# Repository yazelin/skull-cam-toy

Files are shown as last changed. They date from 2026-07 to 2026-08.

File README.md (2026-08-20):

# 骷髏頭凸輪玩具

一根手搖軸、四片凸輪、四個動作(下顎開合、點頭、眼球、轉頭)的木製凸輪機構玩具。

起因是一份 **AI 產生的 1:1 裁切樣板 PDF**。圖面乍看很完整 —— 尺寸線、鑽孔中心、
組裝順序、相位圖全都有,但把向量座標解出來重算之後發現**做不出來**:七個致命問題,
其中「轉頭」那一路即使零件全部完美裁切,自由度也是 0。

這個 repo 是重新推導、逐項驗證過的版本,含 3D 模擬、驗證腳本,以及可以直接下雷切的 1:1 檔案。

**網站:** https://yazelin.github.io/skull-cam-toy/

---

## 拿去做

| | |
|---|---|
| [`cut/cut-all-A4.pdf`](cut/cut-all-A4.pdf) | 1:1 切割檔,A4 五頁,共 47 片 |
| [`cut/cut-*.dxf`](cut/) | 同上的 DXF(雷射軟體通吃,單位 mm) |
| [`cut/cut-*.svg`](cut/) | 同上的 SVG(黑線=切割、藍字=刻字) |
| [`ASSEMBLY.md`](ASSEMBLY.md) | 組裝說明書,十步,每步附「怎麼驗」 |
| [`FINDINGS.md`](FINDINGS.md) | 驗證報告:原始圖面哪裡壞、修正版怎麼驗的 |

材料:3mm 合板 + **只剩兩支圓棒**(Ø6 凸輪軸、Ø4 轉盤撥銷)+ 8×6 方棒(頸脊)+ **兩條橡皮筋**(非加不可,理由見報告)。
導柱、滑銷、軸環全部改成板材卡榫。

每張切割檔底部都有 50mm 校正尺。切之前先量它。

---

## 網站頁面

| 檔案 | 內容 |
|---|---|
| `index.html` | 概覽。招牌是四片**真實凸輪輪廓**在同一根軸上同步轉動,資料就是模擬器用的那一份 |
| `sim.html` | 3D 模擬。可切「原始圖面 / 修正版」,右側有 15 項幾何檢查與完整約束盤點 |
| `heart.html` | **七夕限定「心跳凸輪」**:一片偏心凸輪+一顆會跳的心,20 片 3mm 板、一張 A4 的入門版。含 3D 模擬與 8 項整圈幾何檢查;切割檔 `cut/heart-cut-1.svg/.dxf` 由 `node export-heart.js` 從模型產生;干涉掃描 `node heart-collide.js`(36 角度全零件對,抓過一次相位反向)。模擬全過,**還沒實際切過** |
| `heart-assembly.html` | 由 `HEART-ASSEMBLY.md` 產生:七步組裝+每步驗收+防呆五清單 |
| `heart-print.html` | 心跳凸輪 **3D 列印原生版**:9 種零件印 10 件、全程免膠(D 型軸傳扭力/頂蓋壓入/間隔套定位)。STL 在 `print/`,由 `node export-heart-print-stl.js` 產生;干涉掃描 `node heart-print-collide.js` |
| `heart-print-assembly.html` | 由 `HEART-PRINT-ASSEMBLY.md` 產生:免膠組裝五步+每步 3D 完成狀態圖 |
| `DESIGN-RULES.md` | 機構設計規則檢查表(接頭/配合/導引/約束/驗證順序),新機構動工前逐條過 |
| `assembly.html` | 由 `ASSEMBLY.md` 產生 |
| `findings.html` | 由 `FINDINGS.md` 產生 |

`assembly.html` 與 `findings.html` 是**產生出來的**,不要直接改;改 `.md` 之後跑 `node build-site.js`。

---

## 程式與工具

| 檔案 | 做什麼 |
|---|---|
| `mech.js` | 運動學核心、15 項幾何檢查、約束盤點表(`DOF`) |
| `profiles.js` | 從樣板 PDF 的貝茲曲線解出來的真實輪廓(頭骨、下顎、兩片凸輪) |
| `sim.html` | three.js 場景。每片木板都登記自己的「2D 外形 + 孔 + 厚度」,供掃描與出圖用 |
| `collide.js` | 干涉掃描:板內佈 1mm 網格取樣點,曲柄轉一圈取 72 個角度,兩兩互測 |
| `bom.js` | 從模型撈零件表 |
| `export-cut.js` | 從模型產生 SVG + DXF 切割檔 |
| `build-site.js` | Markdown → 網站頁面 |

全部需要本機 HTTP:

```bash
python3 -m http.server 8099        # 然後開 http://127.0.0.1:8099/
node collide.js                     # 干涉掃描
node bom.js                         # 零件表
node export-cut.js                  # 重出切割檔
node build-site.js                  # 重出網站頁面
```

**切割檔是從 3D 模型直接撈出來的,不是另外畫的** —— 模型改了重跑一次就同步,不會有「圖跟模型對不起來」的問題。

---

## 目前的驗證狀態

```
零件自檢                 每個孔都完全落在輪廓內
肉厚自檢                 孔↔孔、孔↔輪廓都 ≥ 2mm
單件自檢                 沒有「同一零件被拆成多片」
15 項幾何檢查            全過
41 片木板 / 136,125 點    轉一圈 72 個角度   零干涉
四組凸輪接觸間隙          0.00 mm
轉頭叉口                  上緣 0.20 / 下緣 0.20 mm,叉底剩 3.0 mm
約束盤點                  只剩兩處力封閉(下顎、眼球推桿)→ 用橡皮筋
```

還沒做:實際切過。榫孔留單邊 0.1mm,雷射有割縫可能偏鬆,建議先切一組榫試配。

---

## 授權

MIT © 林亞澤。原始樣板 PDF 的著作權屬原作者;本 repo 的幾何是重新推導的。

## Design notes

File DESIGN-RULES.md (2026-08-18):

# 機構設計規則(從骷髏頭與心跳凸輪的實戰蒸餾)

新機構動工前逐條過;這是設計檢查表,不是事後參考。每條都對應一次真實翻車。

## 接頭
- 薄板**對接黏不住**:任何「一條邊碰一條面」的接法,膠合面積趨近零 → 一律榫接/搭接/叉夾,要有互穿的料。(骷髏下顎受推板 0mm²;心跳假接頭)
- 十字/錯位搭接:兩邊的槽**不能疊在同一段空腔**,要錯開,讓 A 的實心填 B 的槽、B 的實心填 A 的槽。畫完自問:**x、y、z 三個方向各由哪個面擋住?**答不出來的方向就是會掉的方向。
- 尖的、窄的零件別在尖端開槽:先確認開槽處的實際料寬(從輪廓量,不是想像)。

## 配合與間隙
- 滑動配合:單邊 0.3mm 起跳(3mm 板實證值);膠合定位配合:單邊 0.1~0.2。
- **任何「靠緊、貼緊」的組裝指令 = 零間隙警報**:自治具黏法要寫墊隙(桿身包一層紙,乾後抽掉)。
- 板材標 3mm 實際 2.8~3.2;疊層會再加誤差。指南要寫「疊完磨齊、裝前試滑」。
- 雷切 kerf 讓配合再鬆 0.1~0.2:留隙+上膠的設計吃得下,緊配吃不下。

## 滑動導引
- 導引嚙合深度 vs 懸臂(抽屜法則):懸臂/嚙合 > 2.5 會卡死(木件上蠟)。單一 3mm 板厚的槽幾乎一定不夠,要導套或雙導點。
- 接觸點會游走的(偏心凸輪 ±e),承接面寬度 = 游走範圍 + 兩側各 ≥2mm。
- 軸向對位靠「加寬其中一方」吃公差:凸輪比推桿厚 ≥2mm,黏歪也磨得到。

## 約束
- 干涉掃描證明「不會穿過」,**不證明「被固定住」**:每個動件 6 個自由度逐一問靠什麼擋,分「形封閉(形狀,拿不掉)」與「力封閉(重力/彈力,快搖會脫)」。力封閉處寫明回位方案(自重/橡皮筋)。
- 手搖類:手把整圈掃過的空間要淨空(對桌面、對底板、對箱體)。

## 驗證順序(每次幾何改動都跑,不是完工才跑)
1. 零件自檢:孔在輪廓內、肉厚 ≥2mm、輪廓不自交、同名件不拆片
2. 干涉掃描:全零件對 × 整圈角度,取樣點互測
3. 幾何檢查:行程、間隙、防卡滯比,寫成頁面常駐項
4. **接頭特寫目視**:合體+拆解各截一張,親眼確認咬合
5. 相位/方向不用手推符號:從 matrixWorld 取實點驗證
6. 改參數名 grep 全檔零殘留(NaN 靜默毀幾何,不報錯)
7. 最後一層永遠是實物;沒切過就寫「沒切過」

## 心跳凸輪一天六錯的教訓
假接頭、相位反轉、固定件沒進場景、改名殘留 NaN、零間隙組裝指令、片數三改——共同根因:**先宣稱後驗證**。檢查清單只涵蓋想到的;沒過上面 1~4 就說「全綠」,綠的只是自己的盲區以外。

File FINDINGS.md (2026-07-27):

# 驗證報告

驗證對象:`skull-cam-template-PRINTFIX.pdf` —— 一份 **AI 產生的** 1:1 裁切樣板。

圖面看起來很專業:尺寸線、鑽孔中心、裁切線與參考線分層、組裝順序、凸輪相位圖,一應俱全。
問題是它從來沒有被驗算過。

所有數字都是從 PDF 的向量座標直接解出來的,不是目測;所有結論都有對應的可重跑腳本。

> 修正版一樣是 AI 做的。差別不在誰做,在有沒有把每一步拿去驗 ——
> 這份報告裡的每個結論,都對應一支可以重跑的腳本。

---

## 結論

**原始圖面做不出來。** 不是公差問題,是機構本身不成立 —— 其中「轉頭」那一路即使零件全部完美裁切,自由度也是 0,轉不動。

以下數字全部是從 PDF 的向量座標直接讀出來的(`pdftocairo` + content stream 解析),不是目測。1mm = 2.8346 PDF unit。

### 致命(轉不動 / 裝不上)

| # | 問題 | 量到的數字 |
|---|---|---|
| 1 | **轉頭連桿無解** | 偏心銷在垂直面畫圓、轉盤銷在水平面畫圓,兩端都是普通旋轉銷且軸線互相垂直。即使讓轉盤自由轉,連桿長度仍要在 64.3~86.6mm 之間變動。這是缺球接頭的 RSSR 空間連桿,剛性連桿長度無解 |
| 2 | **頂板轉頭槽開錯 90°** | 槽是 16(沿 x)×4(沿 y);偏心銷實際位移是沿 y 走 ±12 = 24mm。連桿一進槽就頂死 |
| 3 | **②點頭凸輪刮底板** | R22 偏心 8 → 掃出半徑 30;軸心只有 30 高。間隙 0mm |
| 4 | **點頭升降板落在盒子外面** | 從動桿 B 長 86mm → 升降板頂端 z=130~146,頂板面 z=93。它被推到頭部要待的位置。板長應該約 24mm |
| 5 | **頸柱三個尺寸** | 頂板 Ø8 / 頸柱轉盤 Ø6 / 點頭升降板根本沒開頸柱孔(只有 3 個 Ø4) |
| 6 | **連桿第二個孔畫在零件外** | 下顎連桿 55×10,孔在 (6,5) 與 **(6,50)**;轉頭連桿 70×10,孔在 (6,5) 與 **(6,65)**。x/y 寫反,照描會得到只有一個孔的連桿。應為 (49,5) 與 (64,5) |
| 7 | **下顎不會開合** | 頭骨是正面平板,下顎只有一個垂直板面的中心銷 → 只能在板平面內左右擺 |

### 一定要改(不然裝起來很怪)

| # | 問題 | 量到的數字 |
|---|---|---|
| 8 | 推桿豎在臉前面 | 三個從動桿導槽在 y=58,頸柱孔在 y=90 —— 推桿在臉前方 32mm,而且構不到頭裡的下顎和眼球 |
| 9 | 手把孔位置錯 | 前板 Ø8 在 (150,25);凸輪軸是側板 Ø6 在 (57,30)。凸輪軸不會穿過前板 |
| 10 | 盒體夾不起來 | 前後板 180×90(滿寬)+ 側板 114×90(滿深),兩者都取滿尺寸。側板應為 108 |
| 11 | 標註與實形不符 | 頭骨標 84×100,實際輪廓 69.3×91;下顎標 60×34,實際 56.7×29 |
| 12 | 頸柱長度沒給 | 全份圖沒有任何一處寫頸柱多長 —— 而它決定所有推桿的長度 |

---

## 修正版做了什麼

保留原設計的靈魂:一根手搖軸、四片凸輪、四個動作(下顎/點頭/眼球/轉頭)。
凸輪輪廓也沿用原圖(水滴、雙凸、偏心圓)。改的是**傳動路徑**。

### 1. 轉頭:丟掉空間連桿,改成 45° 斜槽
垂直往復 → 繞垂直軸旋轉,本來就需要螺旋、斜齒或斜槽。
`轉頭叉口板`被凸輪**上下強制**帶動 16mm(C 形叉口夾住偏心圓),板上開一條 45° 斜槽;
轉盤的臂末端有一支水平銷插在斜槽裡,板上下 16mm → 銷左右 ±8mm → 臂半徑 30 → **轉頭 ±15.5°**。
全部是平面板 + 一支銷,3mm 板可裁。

### 2. 點頭與轉頭解耦:頸柱做成「方孔花鍵」
轉盤中央開 8×6 方孔,套在同斷面的頸脊上 —— **可以上下滑、不能相對轉**。
於是點頭(上下 8mm)和轉頭(±15.5°)可以同時發生,互不干擾。轉盤本身高度固定在 z=77。

### 3. 頸柱移到頭部後方,做成「脊板」
原設計頸柱走頭部正中央 → 會穿過下顎片和眼球桿。
改成 8 寬×6 厚的扁棒站在 y=66~72(下顎在 54~60、眼球桿在 63~66),再用接合塊黏到頭骨後片。
頭的重心只前伸 12mm,8mm 斷面撐得住。

### 4. 頭裡的零件改「頂推 + 重力回位」,不用銷接
頭會上下 8mm 又左右轉 ±15.5°,任何從底座上來的**銷接**連桿都會被扭死。
改成:推桿頂端只是「頂」在下顎/眼球桿的受推板上,靠重力回位。
頭轉的時候,接觸點在受推板上滑一下就好 —— 已驗證接觸點跑動範圍在受推板內
(下顎 x 68.1~73.4 / 受推板 62~86;眼球 x 52.6~58.0 / 受推板 42~70)。

### 5. 下顎改「垂直下滑」
正面平板的頭骨,下顎要開合就得往下滑,不能單銷旋轉。
下顎加兩支「升支」(像真的下顎骨),升支上開 23mm 滑槽,套在頭骨主片的兩支 Ø4 銷上。
下顎張開 = 凸輪 11.2mm + 點頭 8mm,相對頭部總行程 11.6mm,槽長 24mm 夠。

### 6. 凸輪軸抬高、升降板進盒子裡
軸心 z=30 → **36**(②凸輪最大半徑 28,留 8mm 間隙)。
升降板改成一片水平板直接躺在點頭凸輪上,位置縮到 x=78~118 完全避開推桿(不用開缺口)。
兩支導柱下插底板、上插中段導板,防止它歪與轉。

### 7. 推桿加厚到 6mm
眼球推桿全長 114mm,3mm 板會抖。6mm 板抗彎剛度是 8 倍(t³)。
導引點:頂板 + 中段導板 z=70。

---

## 修正版關鍵尺寸

```
盒體      180(x) × 114(y) × 90(z),板厚 3;側板改 108 深
凸輪軸    y=57, z=36, Ø6
凸輪 x    眼球 54 / 下顎 70 / 轉頭 124 / 點頭 110(必須與推桿同 x)
凸輪      眼球=雙凸 r12~18(每轉兩次) 下顎=水滴 r14.8~26
          轉頭=偏心 R20 e8 → r12~28   點頭=偏心 R12 e4 → r8~16
相位      下顎 0° / 點頭 90° / 眼球 180° / 轉頭 270°
推桿長    下顎 57 / 眼球 117,厚 6mm;寬腳只留 6mm 高
頸脊      8 寬 × 6 厚,y=69,由升降板頂起
轉盤      下盤 z=84~87 / 凸台 87~93(穿頂板)/ 壓片 93~96;方孔 8.6×6.6,撥銷半徑 30、z=82.5
斜槽      45°,銷 y = (82.5 − 板底高) + 42.5;叉口高 40.4(夾 Ø40 偏心圓)
頭骨      主片 y=51~54 與 60~63;下顎 54~60(6mm);眼球桿 63~66
          頭骨底面 z=125(+點頭 0~8)
```

## 實測動作(模擬跑一整圈)

| 曲柄 | 點頭 | 下顎開 | 轉頭 |
|---|---|---|---|
| 0° | 4.0 | 8.3 | 0° |
| 60° | 0.5 | 10.7 | −13.4° |
| 120° | 0.5 | 3.4 | −13.4° |
| 180° | 4.0 | 1.1 | 0° |
| 240° | 7.5 | 3.5 | +13.4° |
| 300° | 7.5 | 5.9 | +13.4° |

四個動作錯開,連續無跳動。

---

## 干涉掃描(不是用眼睛看的)

「檢查 15 項全過」只證明我**想到的**那 15 個配對沒問題,不等於沒干涉。
所以另外做了一次全零件掃描:每片木板登記自己的「2D 外形 + 孔 + 厚度」,
在板內佈 1mm 網格取樣點,曲柄轉一圈取 72 個角度,兩兩互測「A 的點有沒有落進 B 的實體裡」。
29 片木板、約 12 萬個取樣點。留 1mm 容差,所以「貼合接觸」不算干涉。

第一次掃出 31 組。扣掉腳本自身的兩個問題(長條料只取樣 3 層會漏、原始圖面那組零件混進來)之後,
**真正的設計錯誤有這些,都已修正**:

| 掃到的 | 真正的原因 | 修法 |
|---|---|---|
| 下顎凸輪 ✕ 點頭升降板 | **下顎凸輪在 x=84,但下顎推桿在 x=70** —— 推桿根本沒踩在自己的凸輪上 | 凸輪移到 x=70 |
| 中段導板 ✕ 下顎/眼球推桿 | 推桿下段「寬腳」16mm 高,會頂到 z=64 的導板;導板的槽只讓窄桿身過 | 寬腳降到 6mm、導板抬到 z=70 |
| 推桿 ✕ 受推板(下顎、眼球) | 推桿頂端**穿進**受推板 2mm,而不是頂在它底面 | 下顎推桿 60→57、眼球推桿 122→114 |
| 頸脊 ✕ 轉盤 / 轉盤臂 | 我把頸脊做成「不會轉」,但方孔花鍵的重點就是它要跟著轉;轉盤臂還從頸脊斷面裡長出來 | 頸脊跟著轉;臂改成從半徑 8 才起算 |
| 頂板/升降板的頸脊孔 | 8×6 斷面轉 ±15.5° 時外廓會脹到 9.4×8.0,原本 9.2×7.2 的孔會卡死 | 孔放大到 11×9.6 |
| 頸脊接合塊 ✕ 下顎 / 頭骨主片 | 接合塊做太厚,咬進下顎片 1mm、埋進頭骨主片 | 改成剛好填在頭骨後片與頸脊之間的 3mm |
| 眼球橫桿 ✕ 連接片、受推板 | 我把同一個零件畫成兩片疊在同一個平面上 | 併成一片 L 形;受推板改成對接不是重疊 |

修完重掃:**轉一整圈、72 個角度、零干涉。**

重跑掃描:`node collide.js`(需要本機 HTTP 開著)。

## 約束盤點(第二輪:亞澤指出「這樣不會掉出來嗎」)

干涉掃描只證明「零件不會互相穿過」,**沒有**證明「零件被固定住」。這是兩件事。
所以又做了一次逐件的自由度盤點:每個動件的 6 個自由度分別由什麼約束,
並且區分 **form(形封閉,靠形狀,拿不掉)** 與 **force(力封閉,靠重力,快搖或翻倒會脫開)**。

盤出來的問題與修法:

| 問題 | 修法 |
|---|---|
| **轉頭板垂直方向完全沒約束** —— 凸輪只能把它頂上去,沒有任何東西把它壓回來(它不像其他推桿有零件的重量壓著) | 改成 **C 形叉口(Scotch yoke)**:上下兩條平行邊夾住 Ø40 偏心圓,**上下都是強制驅動**。實測間隙 0.20mm、叉底離凸輪 3.0mm |
| **凸輪軸可以沿軸向抽出來** | 兩顆 Ø14 軸環抵住側板內側 |
| **轉盤軸向沒固定**,原本只畫了一個裝飾用的軸承環 | 改成 Ø20 凸台穿過頂板 Ø20.6 孔,下盤在頂板下、壓片在頂板上 → 被頂板夾住 |
| **升降板被三個讓位缺口切成四段**(缺口貫穿整個板深) | 把升降板縮到 x=78~118,完全避開推桿與轉頭板 → 一個缺口都不用開 |
| **升降板的兩支導柱沒有對應的孔**,而且上端懸空 | 板上開 Ø4.8 孔;導柱下插底板、上插中段導板,兩端都有支撐 |
| **下顎受推板沒接到下顎** —— 它停在 y=62,下顎片在 y=54~60,中間空 2mm | 受推板改從下顎片背面 y=60 接出去 |
| 頸脊只靠兩片 3mm 板導引,基距 13mm,會晃 | 轉盤凸台做成 12mm 高的方孔,直接當頸脊的導套 |
| 撥臂 7mm 寬卻要穿 5.2mm 的斜槽 | 撥臂只到半徑 26,改由 Ø4 撥銷穿槽 |

修完仍然是零干涉。完整的盤點表在網頁右側「約束盤點」區,或看 `mech.js` 的 `DOF`。

**還是 force(力封閉)的地方,只剩兩處**,兩處都建議加回位橡皮筋:
- 眼球推桿下行只靠眼球橫桿自重 —— 最弱的一環
- 下顎推桿下行只靠下顎自重(比較重,但快搖一樣會跳)

點頭升降板雖然也是力封閉,但壓著它的是整顆頭的重量,不必處理。

## 下顎到底靠什麼撐著(第三輪)

**你猜對了:支撐就在兩片臉之間。**

- 下顎片(6mm)夾在兩片頭骨主片(y=51~54 與 60~63)之間 → 前後方向被夾住
- 下顎向上長出兩支「升支」,升支上各開一條 23mm 滑槽
- 兩支 Ø4 銷穿過**兩片臉 + 升支**(z=156,x=76 與 104)→ 下顎吊在銷上,只能上下滑
- 滑槽兩端就是限位:推桿掉下去,下顎最多滑到槽底,掉不出來

**但你第二個看法也對:白色受推板原本沒接到下顎。**

原本受推板在 z=119~122、下顎片從 z=122 起 —— 兩者只有「一條邊碰一條邊」,
膠合面積 **0mm²**。等於推桿在推一片沒黏住的板子。

因為老師給的板子薄,對接(butt joint)本來就不牢,所以改成**榫接**:

- 下顎片底部中央長出兩個 5×4 的**榫耳**(x=84~89、91~96,z=119~123)
- 受推板做成 T 形,前橫條伸到 x=100 套住榫耳,後臂只到 x=84 讓開頸脊
- 榫耳穿過受推板的榫孔再上膠
- 眼球受推板同樣處理(一個 6×3 榫,橫桿左端下伸到 z=164 讓榫孔四周都有料)

榫耳的位置不能亂放:下顎是碗形,下緣從中央 z=122 往兩側一路翹到 z=141。
只有 x=84~96 那段接近平底,榫接得在那裡才有實料。

榫接的膠合面是榫的四個側面 + 對接面,薄板也黏得住;而且兩個零件都還是平板,一樣好裁。

配合公差單邊 0.1mm。掃描器會看到榫在孔裡,那是刻意的,不是干涉。

## 3mm 板的零件表(直接從模型撈出來的)

**3mm 就是這份設計的原生厚度,不用改任何尺寸。** 全部的驗證都是在 3mm 下跑的。
重新產生這張表:`node bom.js`(需要本機 HTTP 開著)。

| 零件 | 外形 mm | 數量 | 3mm 板做法 |
|---|---|---|---|
| 底板 | 180 × 114 | 1 | 1 層 |
| 前板 / 後板 | 180 × 90 | 各 1 | 1 層 |
| 左 / 右側板 | 108 × 90 | 各 1 | 1 層 |
| 頂板 | 180 × 114 | 1 | 1 層(含 2 導槽 + 轉頭槽 + Ø20.6 轉盤孔) |
| 中段導板 | 112 × 45 | 1 | 1 層 |
| 轉頭導片 | 28 × 13 | 2 | 1 層,黏在頂板下形成通道 |
| 曲柄臂 | 16 × 62 | 1 | **2 層** |
| 下顎凸輪(水滴) | 39 × 43 | 1 | 1 層 |
| 眼球凸輪(雙凸) | 36 × 24 | 1 | 1 層 |
| 轉頭凸輪(偏心圓 R20 e8) | 40 × 40 | 1 | 1 層 |
| 點頭凸輪(偏心圓 R12 e4) | 24 × 24 | 1 | 1 層 |
| 下顎推桿 | 39 × 60 | 1 | **2 層** |
| 眼球推桿 | 39 × 117 | 1 | **2 層** |
| 轉頭叉口板 | 44 × 78 | 1 | 1 層(含 Ø40.4 叉口 + 45° 斜槽) |
| 點頭升降板 | 40 × 31 | 1 | 1 層 |
| 頸脊 | 8 × 6 × 110 | 1 | 方棒;或 3mm 疊 2 層再裁 8 寬 |
| 頸脊項圈 | 20 × 16 | 1 | 1 層 |
| 頸脊接合塊 | 20 × 26 | 1 | 1 層,立著黏在頭骨後片與頸脊之間 |
| 轉盤 撥臂 | 18 × 7 | 1 | 1 層 |
| 轉盤 下盤 / 壓片 | Ø30 | 2 | 1 層 |
| 轉盤 凸台 | Ø20 | 1 | **2 層** |
| 頭骨主片 | 68 × 91 | 2 | 1 層(含 2 眼窩 + 鼻孔) |
| 下顎本體 | 54 × 29 | 1 | **2 層** |
| 下顎榫耳 | 5 × 4 | 2 | **2 層**(跟本體同一片裁) |
| 下顎升支 | 8 × 32 | 2 | **2 層**(含 23mm 滑槽) |
| 下顎受推板 | 38 × 38 | 1 | 1 層(T 形,含 2 榫孔) |

| 眼球橫桿 | 76 × 32 | 1 | 1 層(含 2 滑槽 + 1 榫孔) |
| 眼球受推板 | 28 × 26 | 1 | 1 層 |
| 眼球受推板的榫 | 6 × 3 | 1 | 1 層 |

另外要的非板材:Ø6 圓棒(凸輪軸,約 215 長)、Ø4 圓棒(滑銷 ×4、撥銷 ×1)、
Ø4 圓棒(升降板導柱 ×2,長 76)、Ø14 軸環 ×2、Ø7 握把、橡皮筋 ×2。

「2 層疊合」= 兩片 3mm 對貼成 6mm,外形一模一樣,榫孔/滑槽要對齊。

### 板厚不是 3mm 的話

回位力小得可怕(3mm 時下顎自重才 0.045N、眼球桿 0.033N),板越薄越依賴橡皮筋。
推桿的側向勁度跟厚度三次方成正比:1mm 厚受 0.2N 側力會歪 9.5mm,等於一根麵條。
所以推桿、凸輪、軸承、轉盤凸台、頸脊這幾樣**一定要疊回原厚度**,其餘可以照薄的做。
但配合尺寸(頭部夾層位置、槽寬、榫厚)全都綁在板厚上,改材料就要改圖。

## 切割檔自檢(第四輪:亞澤看著雷切圖抓出來的)

前三層驗證(幾何檢查 → 干涉掃描 → 約束盤點)全部通過之後,亞澤打開切割檔,
連續看出三件事,每一件都是前面三層**結構上不可能抓到**的:

### 「下顎有兩個方孔,其中一個還飄在輪廓外」

干涉掃描永遠抓不到這種錯 —— **不存在的材料不會跟任何東西相撞**。
下顎是碗形,下緣從中央 z=122 往兩側一路翹到 z=141;我把榫孔開在 x=66~82,
那裡根本沒有料。

→ 新增**零件自檢**:每個孔都必須完全落在輪廓內。一跑就抓到五個壞孔,
另外三個是誰都沒發現的(轉頭斜槽超出板子上緣、導柱孔破出升降板後緣、
眼球滑槽破出橫桿右緣)。

### 「這眼框有問題嗎」

眼球滑銷孔離眼窩圓心只有 11.7mm,而 11+2.1=13.1 —— **孔咬進眼窩**,差 1.4mm。
零件自檢只看「孔在不在輪廓內」,看不到孔跟孔之間。

→ 新增**肉厚自檢**:量每個孔到其他孔、到外輪廓的最短距離,3mm 板的下限抓 2.0mm。
一跑抓到 13 處,最薄的就是那個眼窩(0.13mm)。滑銷改到 x=62/118,肉厚變 4mm。

### 「受推板有兩個方洞,但下巴沒有兩個凸?還是你用膠的?」

被抓到了:下顎在切割檔裡其實是**三片**(本體 + 兩個榫耳 + 兩支升支),
同名但分開畫,雷切出來要靠膠黏成一片 —— 那榫接就白做了。

→ 寫了外形合併工具(`addRect`),把榫耳與升支沿著輪廓的上下緣併進本體,
下顎變成真正的一整片。同時新增**單件自檢**:同名零件如果同平面又相接,
就是被拆成多片,直接報錯。

零件數 48 → **39 片**(少掉的就是那些本來要用膠黏的碎片)。

### 現在的驗證是四層

| 層 | 抓什麼 | 抓不到什麼 |
|---|---|---|
| 零件自檢 | 孔跑到輪廓外 | 孔跟孔咬在一起 |
| 肉厚自檢 | 孔太靠近、料太薄 | 零件之間的空間干涉 |
| 單件自檢 | 同一零件被拆成多片 | 動起來會不會撞 |
| 幾何檢查 + 干涉掃描 + 約束盤點 | 行程、碰撞、固定 | 上面那三種 |

四層都是被指出來才補的。單一種檢查看起來多完整,都會有它結構上看不到的東西。

## 能不能不用圓棒(第五輪)

亞澤問「有些連接可以不用圓棒、用板材嗎」。逐項判之後,**八成可以**:

| 原本 | 判斷 | 改成 |
|---|---|---|
| 升降板導柱 Ø4 ×2 | 可以,而且更好 | **升降導片** 10×76 板材 ×2。封閉長槽比圓孔多定住一個旋轉自由度 |
| 下顎/眼球滑銷 Ø4 ×4 | 可以 | **滑榫** 3×4 板材小榫 ×4,黏進頭骨主片的方孔 |
| 軸環 Ø14 ×2 | 可以 | 板材圓片(中心 Ø6.2),黏在軸上抵住側板外側 |
| 頸脊 8×6 方棒 | 可以 | 3mm 板疊 2 層再裁 8mm 寬 |
| 手搖握把 Ø7 | 可以 | 3mm 板疊 4 層做 12mm 方柄 |
| **凸輪軸 Ø6** | **不行** | 要在軸承裡連續旋轉。板材疊出來的方軸不是圓的,會卡、會把孔磨成橢圓 |
| **轉盤撥銷 Ø4** | **不建議** | 要一邊沿 45° 斜槽滑、一邊跟著撥臂轉 ±15.5°。方榫在平行槽裡會別死;硬要用就得把槽開寬到容得下對角線,多 1.7mm 曠量 |

改完之後採購清單從七種圓棒縮到**兩支**。

改導片時掃描抓到一次干涉(導片撞到頸脊項圈 2×2×9mm),項圈由 20×16 縮成 16×14 解決。

## 還沒做的

- **回位橡皮筋**(老師說可以用,那就用):眼球推桿與下顎推桿下行只靠重力,轉快了會跳。轉頭板已改成叉口強制驅動,不需要橡皮筋。
- **摩擦與間隙**:模擬是理想剛體,沒算板材毛邊、孔的鬆緊。凸輪與推桿接觸面記得磨圓上蠟。
- **新的 1:1 裁切樣板**:這裡只驗機構,還沒把修正版畫回可列印的 A4 樣板。要的話再說。
- 眼球目前是上下滾(原圖寫「左右溜」)。左右要多一組斜槽,值不值得看你。

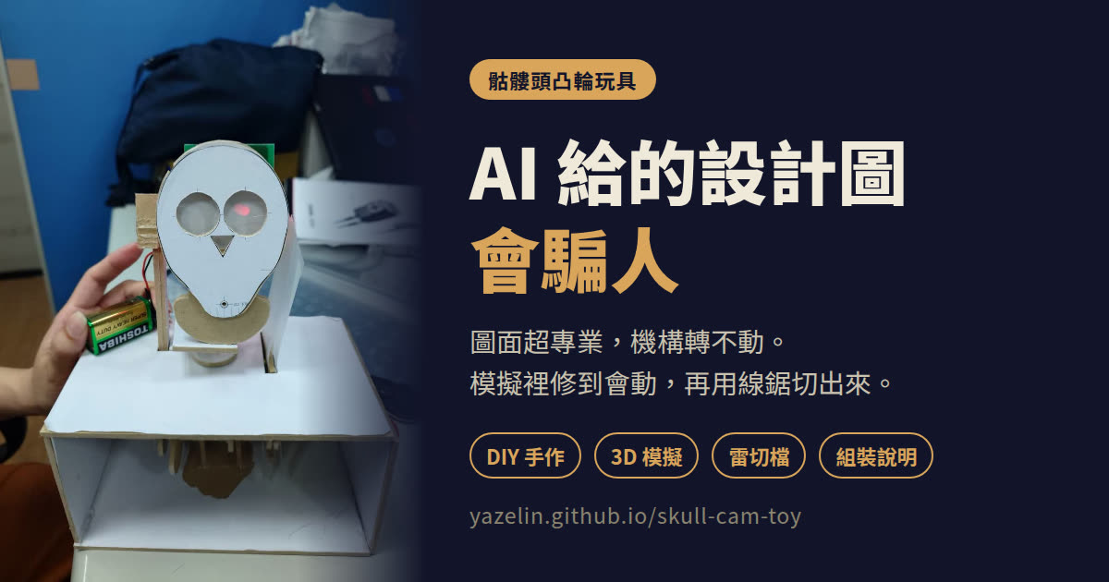
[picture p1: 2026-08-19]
assets/og.jpg

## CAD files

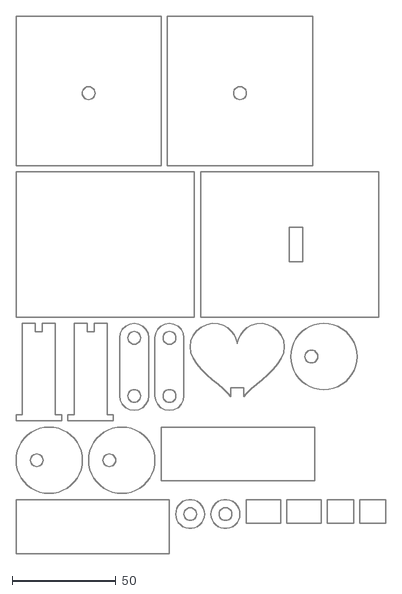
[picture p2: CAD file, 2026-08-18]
cut/heart-cut-1.dxf
178.4 x 259.0

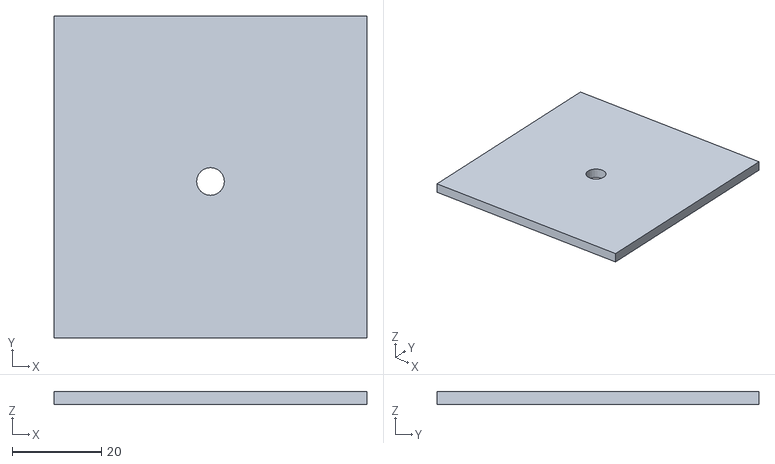
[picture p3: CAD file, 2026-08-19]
print/flat/heart-02-side.stl
70.0 x 72.0 x 3.00

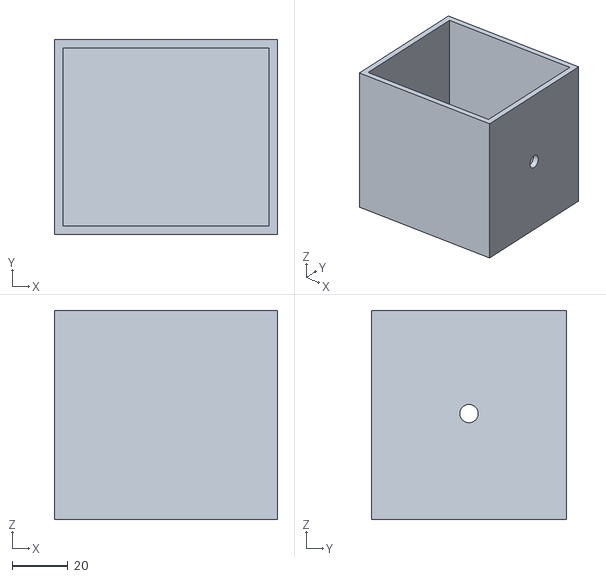
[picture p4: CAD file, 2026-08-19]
print/hp-01-body.stl
80.0 x 70.0 x 75.0

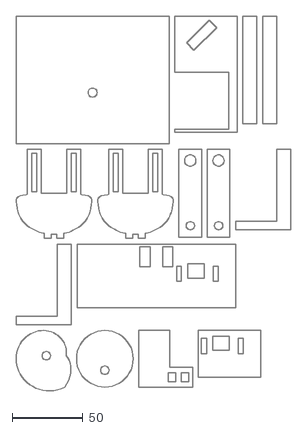
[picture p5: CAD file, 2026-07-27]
cut/cut-4.dxf
194.0 x 264.6

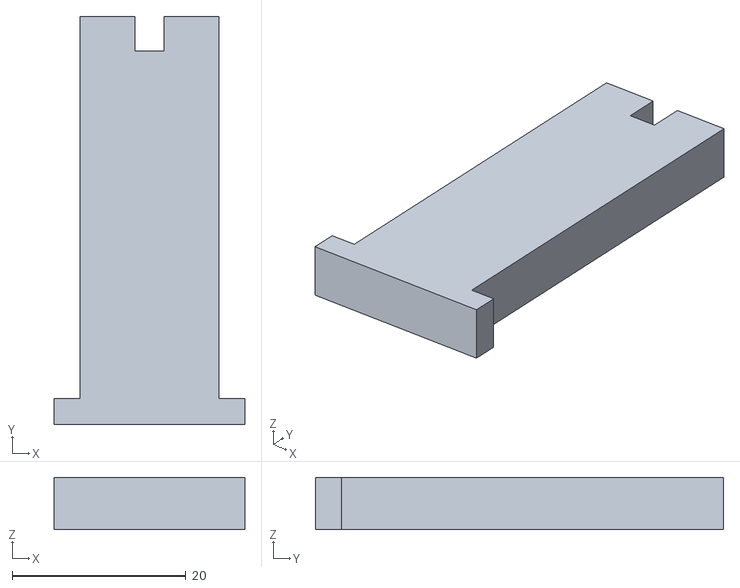
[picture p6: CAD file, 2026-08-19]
print/flat/heart-10-follower.stl
22.0 x 47.0 x 6.00

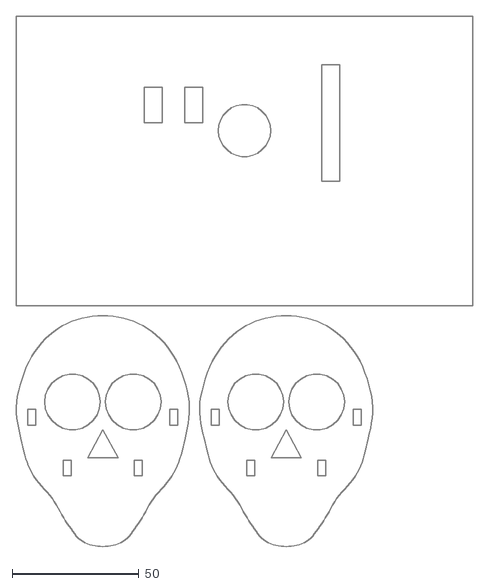
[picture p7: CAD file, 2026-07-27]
cut/cut-2.dxf
180.0 x 209.0

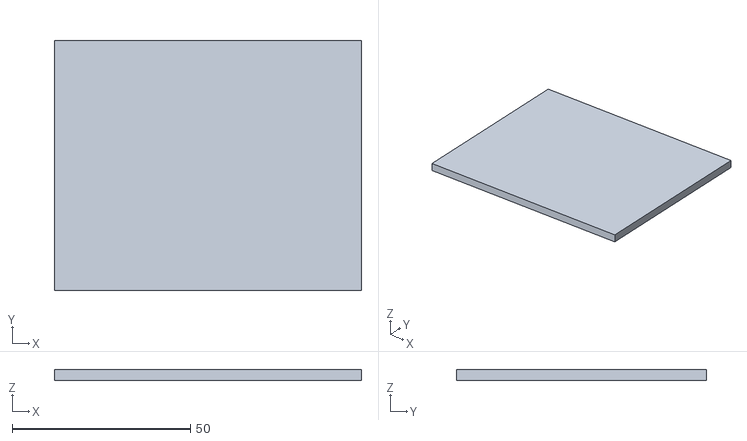
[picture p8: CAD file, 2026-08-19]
print/flat/heart-01-base.stl
86.0 x 70.0 x 3.00

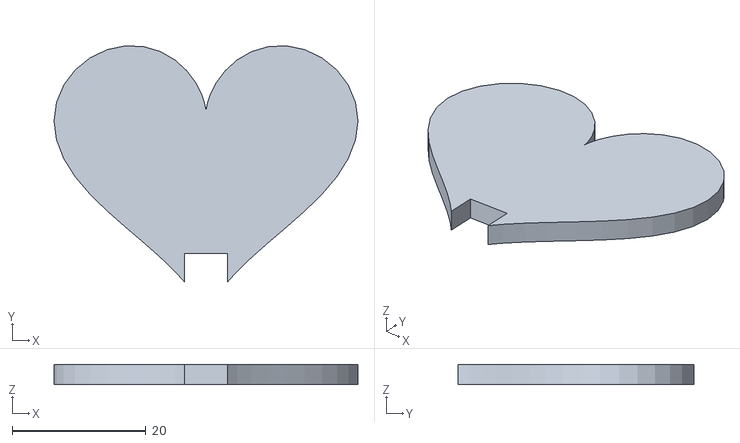
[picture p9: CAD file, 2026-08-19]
print/hp-06-heart.stl
45.4 x 35.3 x 3.00

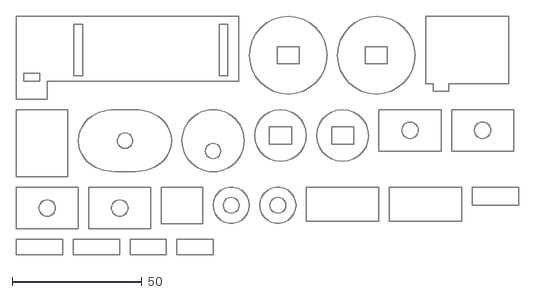
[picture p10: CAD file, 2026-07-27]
cut/cut-5.dxf
194.0 x 92.0

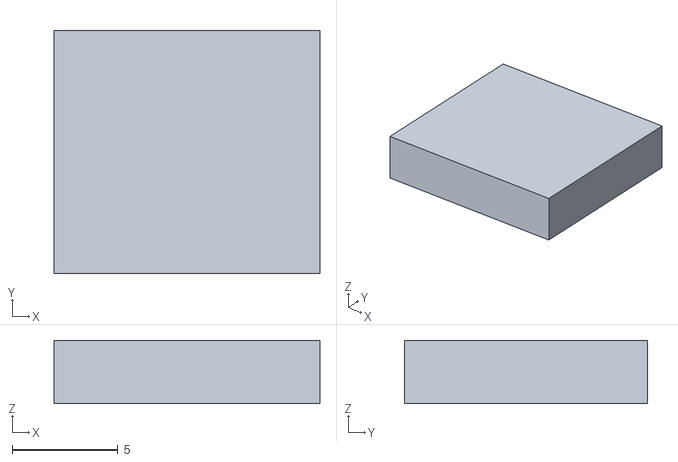
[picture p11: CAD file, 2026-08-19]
print/flat/heart-06-guide-frontback.stl
12.6 x 11.5 x 3.00

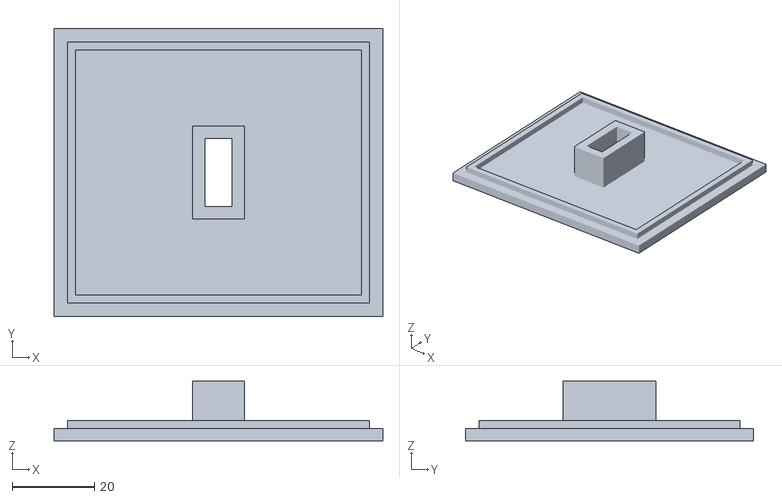
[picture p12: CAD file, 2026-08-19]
print/hp-02-cap.stl
80.0 x 70.0 x 14.5

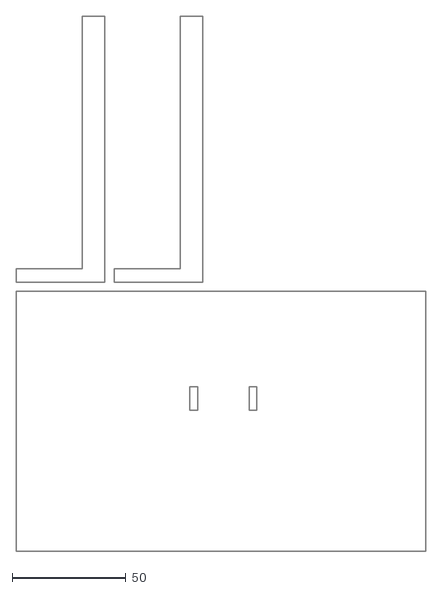
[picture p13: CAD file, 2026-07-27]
cut/cut-1.dxf
180.0 x 235.0

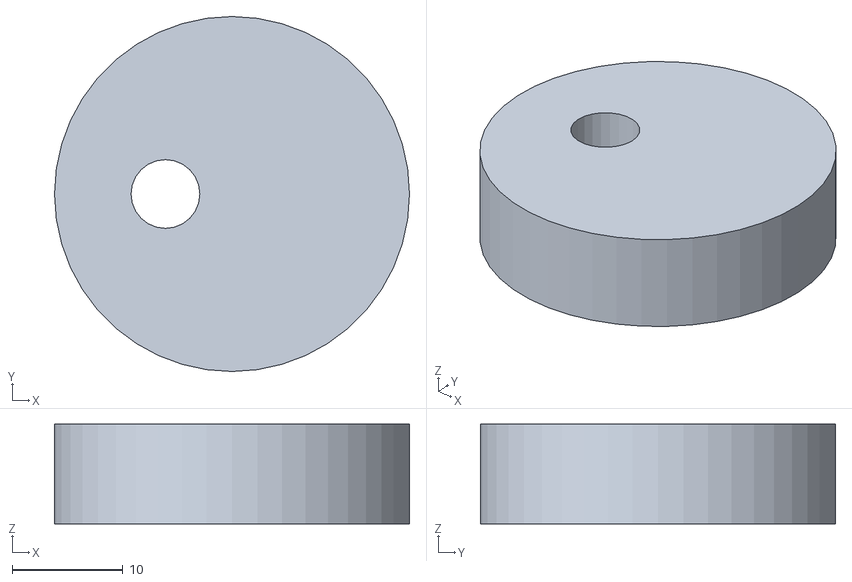
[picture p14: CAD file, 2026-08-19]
print/flat/heart-07-cam.stl
32.0 x 32.0 x 9.00

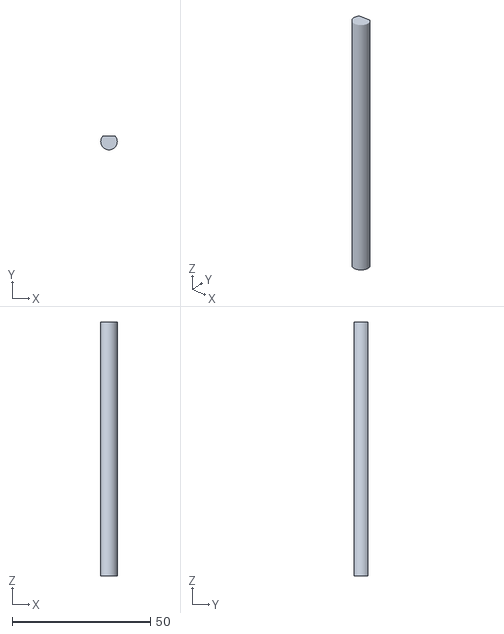
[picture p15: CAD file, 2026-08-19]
print/hp-08-shaft.stl
6.00 x 5.00 x 92.0

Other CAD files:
print/hp-05-follower.stl
cut/cut-3.dxf
print/flat/heart-08-crank.stl
print/hp-09-handle-pin.stl
print/flat/heart-03-top.stl
print/flat/heart-04-skirt.stl
print/flat/heart-05-guide-side.stl
print/flat/heart-09-collar.stl
print/flat/heart-11-heart.stl
print/hp-03-cam.stl
print/hp-04-spacer.stl
print/hp-07-crank.stl

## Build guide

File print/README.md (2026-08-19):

# 心跳凸輪 · 3D 列印版

兩種印法,選一種:

## A. 列印原生版(hp-*.stl,推薦)

跟木板版同一套機構重新設計:**9 種零件、共印 10 件、全程免膠**。
[3D 模擬與逐項檢查](../heart-print.html)、組裝五步都在獨立頁面。

- 箱身(底板+四牆)一體印、頂蓋含導套與壓入唇一體印
- 凸輪/曲柄用 **D 型軸孔**傳扭力,免膠
- 軸環換成**間隔套**:凸輪置中靠套管頂住,裝歪不可能
- 「包紙墊隙」那步不用了:間隙直接印在幾何裡

| 檔案 | 零件 | 件數 | 列印方向 |
|---|---|---|---|
| hp-01-body.stl | 箱身 | 1 | 開口朝上,照檔印 |
| hp-02-cap.stl | 頂蓋 | 1 | 檔已翻好(導套朝上),裝配時翻回 |
| hp-03-cam.stl | 偏心凸輪(D 孔) | 1 | 平躺 |
| hp-04-spacer.stl | 間隔套 | 2 | 站著 |
| hp-05-follower.stl | 推桿 | 1 | 平躺 |
| hp-06-heart.stl | 心 | 1 | 平躺(換紅色料) |
| hp-07-crank.stl | 曲柄臂(D 孔) | 1 | 平躺 |
| hp-08-shaft.stl | 軸(Ø6 帶 D 面) | 1 | 平躺,D 面朝下 |
| hp-09-handle-pin.stl | 手把銷 | 1 | 帽朝下站著 |

## B. 板件直印版(flat/,跟雷切檔同幾何)

木板版的 20 片直接變 STL(疊層件印全厚,合併成 16 件),組裝照[木板版組裝說明](../heart-assembly.html),
一樣要上膠(PLA 用瞬間膠,白膠黏不住)。想跟雷切版完全同款就選這個。檔案在 [`flat/`](flat/)。

## 列印參數(兩版通用)

- PLA、層高 0.2mm、3 層壁、15% 填充,全部免支撐。
- **先印公差測試**:只印一件間隔套(A 版)或軸環(B 版),拿 Ø6 圓棒或印出來的軸試插,
  要「能轉不晃」。太緊就開 XY 孔補償 +0.1~0.2mm 重印,調好再印其餘。FDM 孔會縮,這步不能跳。
- 滑動面(推桿×導套、推桿×凸輪頂面)設計留單邊 0.3mm;印出來有層紋就砂紙輕磨。

> 誠實聲明:兩版都通過模擬三層驗證(逐項幾何檢查/36 角度干涉掃描/STL 逐殼水密+尺寸核對),
> 但**都還沒實際印過**。骷髏頭與心跳凸輪的木板版當初也是同樣狀態,後來切出來如預期會動。印了歡迎回報。

## 重新產生

```
python3 -m http.server 8099          # 開著
node export-heart-print-stl.js       # A 版:從 heart-print.html 的幾何出 hp-*.stl
node export-heart-stl.js             # B 版:從 heart.html 的幾何出 flat/heart-*.stl
node heart-print-collide.js          # A 版干涉掃描(改幾何後必跑)
```

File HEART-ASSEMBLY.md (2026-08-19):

# 七夕心跳凸輪 · 組裝說明

一根手搖軸、一片偏心凸輪、一顆會跳的心。20 片 3mm 板 + 兩段 Ø6 圓棒,升程 12mm。
搭配 [3D 模擬](heart.html) 一起看:拉「爆炸圖」滑桿對照每一步,點「拆解接頭」看心和推桿怎麼咬合。

> 誠實聲明:本設計走完模擬三層驗證(幾何檢查/干涉掃描/零件自檢),**還沒實際切過**。
> 骷髏頭當初也是同樣狀態,後來線鋸切出來如預期會動。你切了,歡迎回報。

## 第 0 步:列印與備料

- 列印描圖:印 [`cut/heart-cut-A4.pdf`](cut/heart-cut-A4.pdf)(一張 A4、1:1),縮放選「實際大小 / 100%」,**不要**選「符合頁面」。雷切:用 [`heart-cut-1.svg`](cut/heart-cut-1.svg) 或 [`heart-cut-1.dxf`](cut/heart-cut-1.dxf),黑線=切割、藍字=刻字。
- 印出後量左下角校正尺:**50mm 線段必須剛好 50mm**,不對就調印表機縮放重印。
- 材料:3mm 木板或厚紙板一張 A4 的量、Ø6 圓棒兩段(軸 92mm、手把 34mm;竹筷可替代,骷髏頭實作就是竹筷)、白膠、砂紙、一張紙條(第 5 步當墊片用)。
- 板材標 3mm 實際常是 2.8~3.2mm:疊層件黏完若超過 6.4mm,先磨薄再裝。
- 雷切的話:kerf 會讓配合再鬆 0.1~0.2mm,本設計全走「留隙+上膠」,鬆一點無害。
- **膠水用白膠(木工 PVA)就對了**:乾透後比木材本身還強,膠層薄不吃間隙。**不要用熱熔膠**黏配合面——膠層厚 0.5~1mm 會把留好的間隙全吃掉,受力久了還會剝。趕時間就用快乾木工膠。
- **圓棒/竹筷的黏合段先用砂紙磨毛**:竹子表面光滑,白膠咬不住,磨毛才牢(凸輪孔、軸環、曲柄孔、手把孔都適用)。

## 第 1 步:疊層件先黏

凸輪 3 片(疊 9mm)、推桿 2 片(疊 6mm)、曲柄臂 2 片(疊 6mm)各自疊黏。

- 黏之前拿一小段軸穿過孔當定位銷,孔對孔再壓合;曲柄臂兩孔都穿。
- 乾後把疊層邊緣磨齊,推桿四邊尤其要磨——它之後要在導套裡滑。

**驗**:凸輪穿軸能轉不晃;推桿厚度量起來 ≤6.4mm、寬度 ≤16.4mm。

## 第 2 步:側板立上底板

兩片側板(有 Ø6.2 軸孔的)立在底板上:**左側板距底板左緣 6mm、右側板外面距右緣 0(貼齊)**,軸孔同高同向,黏牢。
再把兩片**前後裙板**(74×26)卡進兩側板之間、貼齊底板前後緣黏好——結構閉環,箱體才不會左右歪斜。

**驗**:拿軸同時穿過兩孔,能自由轉、不彆手;抓住兩側板前後搖,不晃。

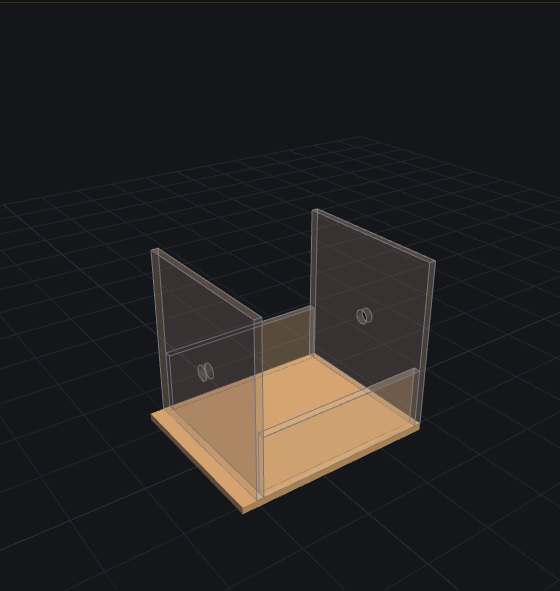
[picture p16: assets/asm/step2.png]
第 2 步完成:側板立上底板


## 第 3 步:穿軸鏈(順序不能反)

軸從**左側板外**往內穿 → 套**左軸環** → 套**凸輪**(先不上膠) → 套**右軸環** → 穿出**右側板**。

- 凸輪推到正中:距兩側板內面各約 34mm。置中才有 ±1.5mm 的軸向容差,推桿不會踩空。
- 定位好後:凸輪中孔**整圈上白膠**(軸的這段先磨毛);兩枚軸環分別貼側板內側、黏在軸上(擋軸向滑動)。

**驗**:搖軸,凸輪跟著轉、軸不左右滑動。

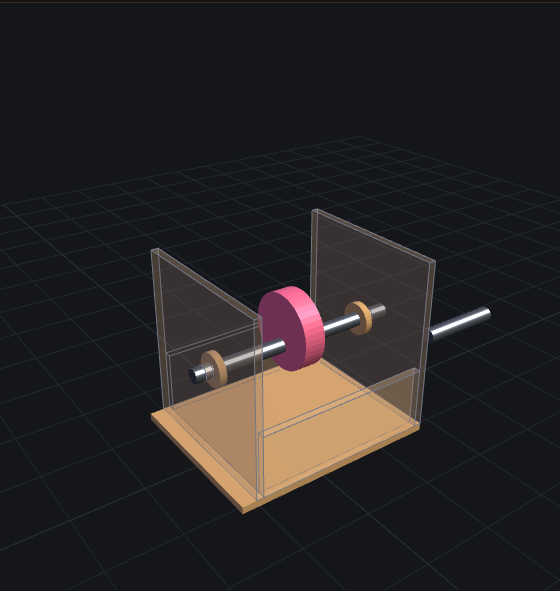
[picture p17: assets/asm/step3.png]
第 3 步完成:軸鏈就位,凸輪置中


## 第 4 步:曲柄與手把

曲柄臂套軸右端,與右側板**留 1~2mm 縫**再黏死;手把段插進臂另一端的孔黏牢。

**驗**:搖一整圈,曲柄與手把不掃到底板、不擦側板。

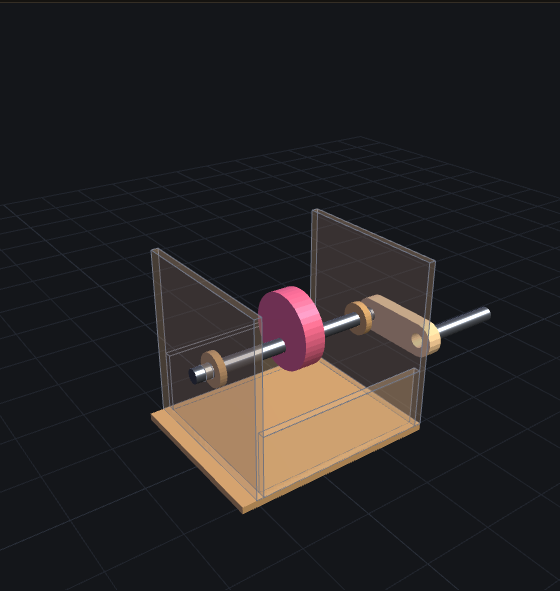
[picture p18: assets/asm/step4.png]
第 4 步完成:曲柄與手把裝上


## 第 5 步:推桿與導套(最容易裝錯的一步)

1. 推桿 **T 腳朝下**立在凸輪正上方。
2. 頂板**先不上膠**,從桿頂套下(導槽對準桿身)。
3. 桿身**包一層紙**當墊片。
4. 四片導片貼著紙面靠緊:左右兩片夾窄邊、前後兩片擋寬邊,頂邊全部貼齊頂板底面,黏在頂板上。
5. 膠乾後**抽掉紙**——孔道位置準(推桿自己就是治具)、間隙也剛好(紙就是間隙)。

**驗**:手抽推桿上下要順滑;搖軸,推桿升降 12mm 不卡。**過了這關**才把頂板四邊上膠、蓋牢箱體。

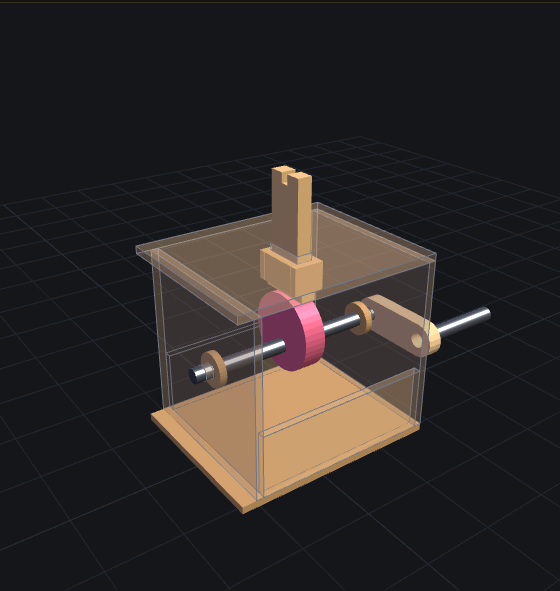
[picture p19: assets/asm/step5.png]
第 5 步完成:推桿穿過導套與頂板


## 第 6 步:裝心

心的底槽對準推桿頂端叉槽,往下沉到底(心槽頂面坐在叉槽底面),四面上白膠。
這是錯位搭接:心的槽壁跨住推桿(左右)、叉齒夾住心板(前後)、槽頂面定深(上下)。

**驗**:搖軸,心上下跳 12mm,四個接觸面都吃到膠。

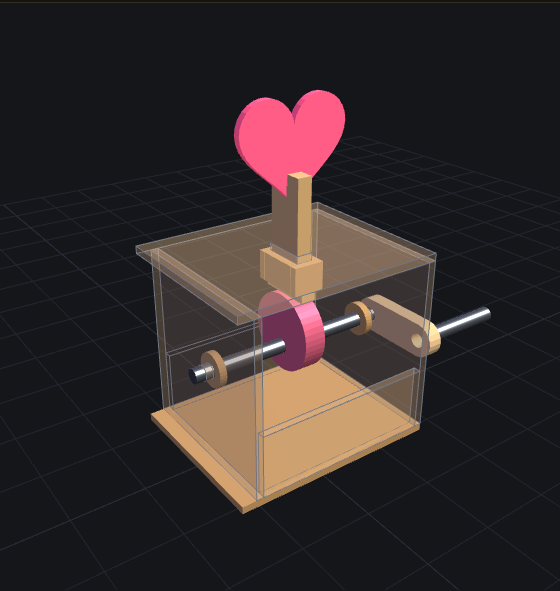
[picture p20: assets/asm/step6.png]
第 6 步完成:整機


## 第 7 步:調校

- 推桿桿身與凸輪頂面**磨圓、上蠟**(蠟燭塗一塗就行),滑起來才順。
- 回位靠自重就夠:偏心 6mm 要搖到約每秒 6 轉(386rpm)心才會跳離,手搖通常 1~2 轉/秒,餘裕三倍以上。
- 卡卡的:先查導套四面間隙(磨導片內側),再查凸輪有沒有置中。

## 最容易裝錯的五件事

1. 導片「靠緊黏」**沒墊紙** → 零間隙,100% 卡死
2. **先黏死頂板**才想放推桿 → T 腳穿不過導槽,順序不能反
3. T 腳**裝反朝上** → 沒有接觸面,心不會跳
4. 凸輪**沒置中** → 吃掉 ±1.5mm 軸向容差,推桿踩空
5. 曲柄臂**貼死側板** → 整圈摩擦,要留 1~2mm 縫

## 零件表

| 零件 | 外形 mm | 片數 |
|---|---|---|
| 底板 | 86 × 70 | 1 |
| 側板(含 Ø6.2 軸孔) | 70 × 72 | 2 |
| 前後裙板(閉環箱體) | 74 × 26 | 2 |
| 頂板(含推桿導槽) | 86 × 70 | 1 |
| 導片(圍成導套) | 16.6×12 ×2、12.6×12 ×2 | 4 |
| 偏心凸輪 R16 e6 | Ø32 | 3(疊 9mm) |
| 推桿(T 型腳+頂端叉槽) | 22 × 47 | 2(疊 6mm) |
| 心(底緣藏一道搭接槽) | 約 44 × 40 | 1 |
| 曲柄臂(兩端 Ø6.2 孔) | 14 × 42 | 2(疊 6mm) |
| 軸環 Ø14(孔 Ø6.2) | Ø14 | 2 |

另需:Ø6 圓棒兩段(軸 92mm、手把 34mm)、白膠。

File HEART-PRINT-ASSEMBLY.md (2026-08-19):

# 心跳凸輪 3D 列印版 · 組裝說明

9 種零件印 10 件,**全程免膠**,升程 12mm。
搭配 [3D 模擬](heart-print.html) 一起看:用「顯示/隱藏」藥丸對照每一步,拉「爆炸圖」看全部零件怎麼疊。

> 誠實聲明:本設計通過模擬三層驗證(逐項幾何檢查/干涉掃描/STL 水密核對),**還沒實際印過**。
> 木板版當初也是同樣狀態,後來線鋸切出來如預期會動。你印了,歡迎回報。

## 第 0 步:列印與公差測試

- STL 都在 [STL 下載頁](print/):hp-01 到 hp-09,共 10 件(間隔套印 2 件),清單見 `MANIFEST.txt`。
- PLA、層高 0.2mm、3 層壁、15% 填充,全部平躺免支撐。列印方向照 [print/README.md](print/README.md) 的表。
- **先只印一件間隔套當公差測試**:軸(印出來的或 Ø6 圓棒)要能插進去「轉動不晃」。
  太緊就在切片軟體開 XY 孔補償 +0.1~0.2mm 重印,調到剛好,**再**印其餘零件。FDM 孔會縮,這步不能跳。
- 心那件換紅色料印。
- 不想印軸:Ø6 圓棒或竹筷可替代,但圓棒沒有 D 面,凸輪和曲柄就得各點一滴瞬間膠固定。

## 第 1 步:穿軸鏈

箱身頂是開的,凸輪和兩個間隔套先從頂口放進箱內。
軸從**右牆外**往內穿 → 箱內依序串:**右間隔套** → **凸輪**(D 孔對準軸的 D 面) → **左間隔套** → 穿出**左牆**。

- 凸輪 D 孔要對準 D 面再推,別硬壓,壓裂孔就要重印。
- 兩個間隔套把凸輪自動夾在正中,不用量尺寸。

**驗**:搖軸,凸輪跟著轉(D 面咬合,免膠);軸向左右推,游隙約 1mm、不會大幅滑動。

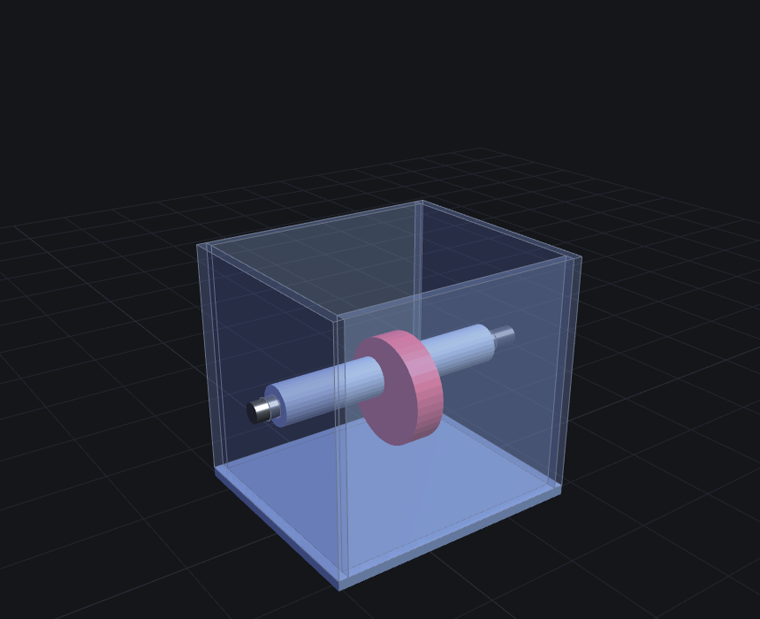
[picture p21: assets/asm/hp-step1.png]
第 1 步完成:軸鏈就位,間隔套夾住凸輪


## 第 2 步:放推桿

推桿 **T 腳朝下**,立在凸輪正上方。

**驗**:推桿底面貼著凸輪頂,直立不歪。

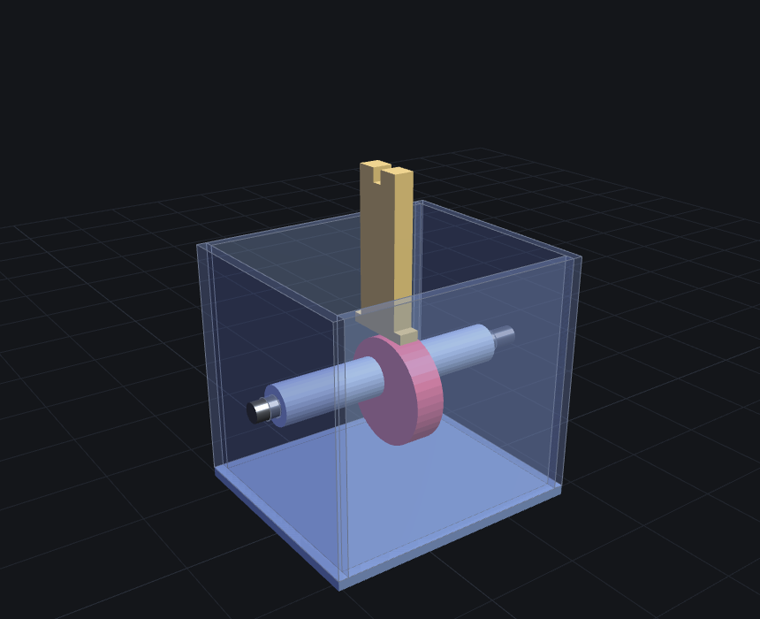
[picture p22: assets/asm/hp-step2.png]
第 2 步完成:推桿立上凸輪


## 第 3 步:蓋頂蓋

頂蓋的**導套對準推桿**從桿頂套下,四邊內唇對準箱口,壓到底。
(順序不能反:T 腳寬 22mm 穿不過導槽,**先放推桿才能蓋頂蓋**。)

**驗**:手抽推桿上下要順滑;搖軸,推桿升降 12mm 不卡。緊了磨唇外緣,鬆了唇上貼一圈紙膠帶。

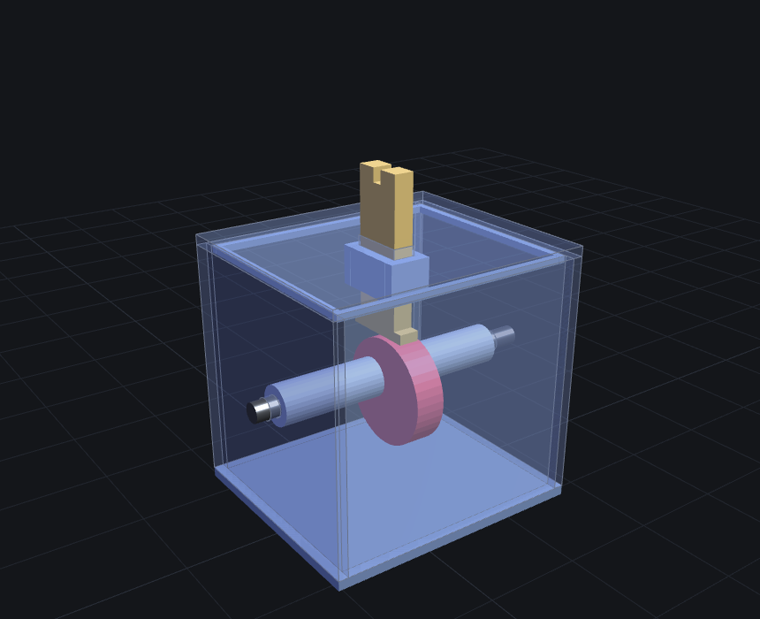
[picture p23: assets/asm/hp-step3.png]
第 3 步完成:頂蓋壓入,推桿穿出導槽


## 第 4 步:曲柄與手把銷

曲柄的 **D 孔**壓上右邊露出的軸端,與右牆**留 1~2mm 縫**;手把銷(帽朝外)壓進曲柄另一端的孔。

**驗**:搖一整圈,曲柄和手把不掃桌面、不擦牆。

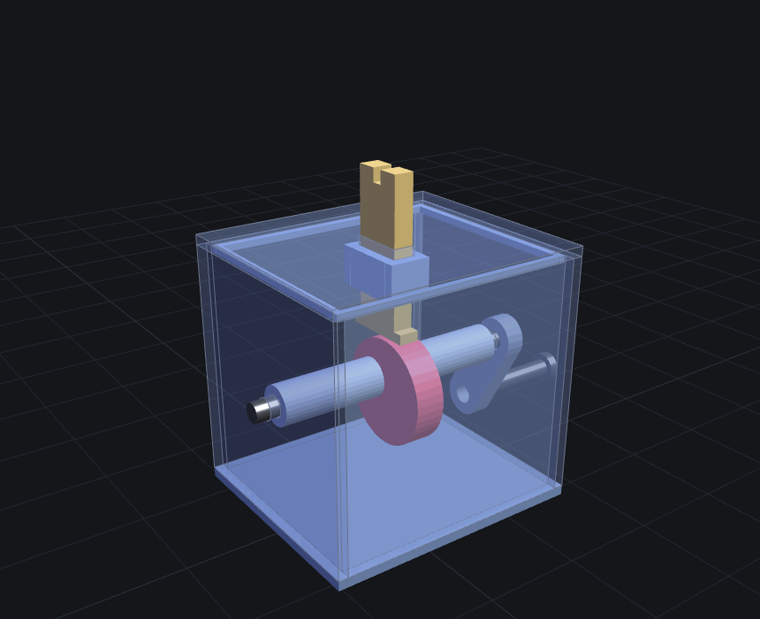
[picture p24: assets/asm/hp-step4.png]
第 4 步完成:曲柄與手把裝上


## 第 5 步:裝心

心的底槽對準推桿頂端叉槽,往下沉到底(槽頂面坐在叉槽底面)。
錯位搭接:心的槽壁跨住推桿(左右)、叉齒夾住心板(前後)、槽頂面定深(上下)。

**驗**:搖軸,心上下跳 12mm。配合太鬆會晃的話,叉槽裡點一滴瞬間膠,非必要。

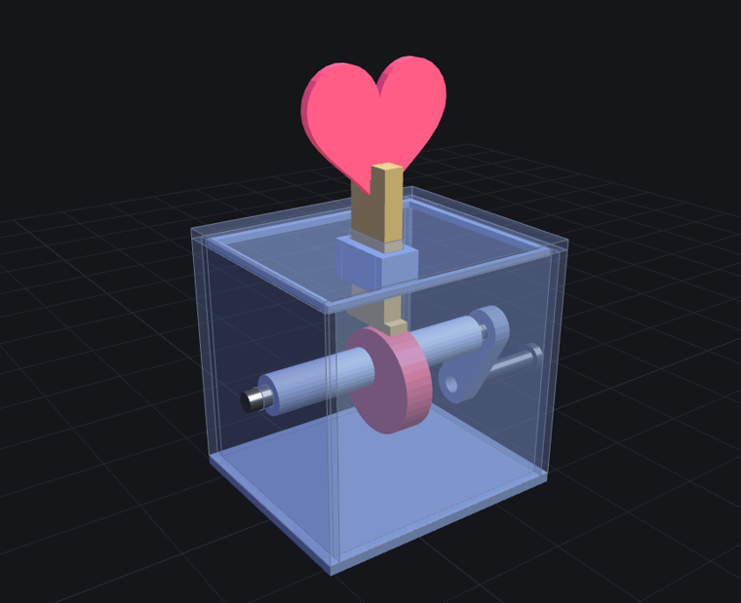
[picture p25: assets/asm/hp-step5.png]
第 5 步完成:整機


## 調校

- 推桿桿身與凸輪頂面的層紋用砂紙輕磨,滑起來才順;乾性潤滑(蠟燭塗一塗)更好。
- 卡卡的:先查導套四面(磨推桿稜線),再查頂蓋有沒有壓到底。
- 回位靠心與推桿自重:手搖 1~2 轉/秒餘裕三倍以上,不需要彈簧。

## 最容易裝錯的五件事

1. **跳過公差測試**直接印全套 → 孔太緊全部重印
2. D 孔**沒對準 D 面硬壓** → 撐裂,凸輪報廢
3. **先蓋頂蓋才想放推桿** → T 腳穿不過導槽,順序不能反
4. T 腳**裝反朝上** → 沒有接觸面,心不會跳
5. 頂蓋**沒壓到底** → 導套懸空,推桿行程卡一半

## 零件表

| 檔案 | 零件 | 件數 |
|---|---|---|
| hp-01-body.stl | 箱身(底板+四牆,Ø6.6 軸孔) | 1 |
| hp-02-cap.stl | 頂蓋(含導套與壓入唇) | 1 |
| hp-03-cam.stl | 偏心凸輪 R16 e6(D 孔) | 1 |
| hp-04-spacer.stl | 間隔套 Ø12×32 | 2 |
| hp-05-follower.stl | 推桿(T 型腳+叉槽) | 1 |
| hp-06-heart.stl | 心 | 1 |
| hp-07-crank.stl | 曲柄臂(D 孔+手把孔) | 1 |
| hp-08-shaft.stl | 軸 Ø6×92(帶 D 面) | 1 |
| hp-09-handle-pin.stl | 手把銷 | 1 |

跟雷切幾何相同的「板件直印版」在 [STL 下載頁的 B 區](print/#flat),那個版本照[木板版組裝說明](heart-assembly.html)組,要上膠(PLA 用瞬間膠)。

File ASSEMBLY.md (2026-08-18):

# 骷髏頭凸輪玩具 · 組裝說明書

> 實作註記:線鋸實作版有不少小地方是現場手工修出來的;就算照切割檔雷切,組裝時多半仍需微調修配。圖面與模擬給你九成,最後一成靠現場。

**板厚 3mm。** 所有尺寸都是在 3mm 下驗證過的(15 項幾何檢查 + 全零件干涉掃描)。
換板厚就要重算,不能只換材料。

座標約定(組裝時腦中對一下就好):
`x` = 左右 0~180 · `y` = 前後 0 是前板 · `z` = 上下 0 是底板上表面。

---

## 0 · 材料

**板材**:3mm 合板,A4 五張的量(`cut-all-A4.pdf`,共 47 片)。

**非板材**(要另外買):

| 品項 | 規格 | 數量 | 用在哪 |
|---|---|---|---|
| 圓棒 | Ø6 × 215 | 1 | **凸輪軸 —— 唯一非圓不可的一支** |
| 圓棒 | Ø4 × 20 | 1 | 轉盤撥銷(見下面說明) |
| 方棒 | 8 × 6 × 110 | 1 | 頸脊(也可用 3mm 板疊 2 層再裁 8mm 寬) |
| 握把 | — | 1 | 3mm 板疊 4 層做成 12mm 方柄,或用 Ø7 圓棒 |
| 橡皮筋 | 細 | 2 | 下顎推桿、眼球推桿的回位 |
| 白膠 | — | — | |

**其他連接全部用板材卡榫**,不需要圓棒:

| 原本 | 改成 |
|---|---|
| 升降板導柱 Ø4 圓棒 ×2 | **升降導片** 10×76 板材 ×2,下端插底板、上端插中段導板 |
| 下顎/眼球滑銷 Ø4 圓棒 ×4 | **滑榫** 3×6 板材小榫 ×4(下顎 14 長 ×2、眼球 18 長 ×2),黏進頭骨主片的方孔 |
| 軸環 Ø14 ×2 | **板材圓片** Ø14(中心 Ø6.2)×2,黏在軸上抵住側板外側 |

**為什麼這兩支還是圓的:**
- **凸輪軸**要在軸承裡連續旋轉。板材疊出來的方軸不是圓的,轉起來會卡、會磨橢圓。
- **轉盤撥銷**要一邊沿 45° 斜槽滑、一邊跟著撥臂轉 ±15.5°。
  方榫在平行槽裡會別死;要嘛用圓銷,要嘛把槽開寬到容得下方榫的對角線(會多 1.7mm 曠量)。

---

## 1 · 切割前:先驗印表機

`cut-*.svg` / `cut-all-A4.pdf` 每張底部都有一段 **50mm 校正尺**。
列印或雷切前先量它 —— **不是剛好 50mm 就是縮放跑掉了**,整份都會錯。
列印設定要選「實際大小 / 100%」,不要選「符合頁面」。

---

## 2 · 疊層膠合

切完先把「×2 層」的件兩片對貼成 6mm,**孔和槽一定要對齊**(用一支 Ø4 圓棒穿過孔當定位再上膠)。

要疊的:曲柄臂、下顎推桿、眼球推桿、**下顎**、轉盤凸台、軸承塊 ×2。

單層就好:軸環 ×2、升降導片 ×2、滑榫 ×4。

下顎是**一整片**(本體 + 兩支升支 + 兩個榫耳都在同一個輪廓裡),不是黏出來的。

---

## 3 · 底座

1. 底板(180×114)平放。
2. **前板、後板**(180×90)立在底板前後緣。
3. **左右側板**(108×90)夾在前後板之間 —— 側板是 108 不是 114,就是為了留出前後板的 3+3。
4. **軸承塊**(24×16,6mm)貼在兩片側板**內側**,Ø6 孔對準側板的 Ø6 孔。
   這一步不能省:側板只有 3mm,軸承長度不夠,孔會被磨成橢圓。貼了之後變 9mm。
5. **兩片升降導片**(10×76)插進底板的兩道榫孔,位置 x=78 與 x=104(y=62~72),垂直立好。
   上端等第 6 步蓋中段導板時一起插進去 —— 兩端都有榫,不會歪。

> **驗**:兩片側板的軸孔要左右對齊 —— 拿 Ø6 圓棒穿過去,能輕鬆轉動不卡。

---

## 4 · 凸輪軸與相位(最關鍵的一步)

凸輪軸 Ø6 從左側板穿進去,**由左而右**依序套上:

| 順序 | 零件 | x 位置 | 相位 |
|---|---|---|---|
| 1 | 眼球凸輪(雙凸) | 54 | **180°** |
| 2 | 下顎凸輪(水滴) | 70 | **0°** |
| 3 | 點頭凸輪(偏心 R12 e4) | 110 | **90°** |
| 4 | 轉頭凸輪(偏心 R20 e8) | 124 | **270°** |

**先不要上膠。** 四片都能在軸上轉,留到第 9 步試轉時再定相位。

兩端裝 **Ø14 軸環**,抵住側板外側 —— 不裝的話軸會整根滑出來。

左端裝曲柄臂(Ø6 孔),外側裝 Ø7 握把。

> **驗**:手轉一圈,四片凸輪都不會刮到底板。
> 最險的是轉頭凸輪(最大半徑 28,軸心高 36)→ 應該還有 **8mm** 間隙。

---

## 5 · 升降板與頸脊

1. **點頭升降板**(44×33)兩道長槽套進兩片導片,平放在**點頭凸輪**上。
   > 槽是封閉的,所以同時定住左右、前後與旋轉 —— 這是導片比圓柱好的地方。
2. **頸脊項圈**(20×16)黏在方棒底端。
3. 方棒(頸脊)豎起來,項圈坐在升降板上 —— 只是坐著,不上膠(它要能轉)。

> **驗**:轉曲柄一圈,升降板應該上下走 **8mm**,而且不會歪、不會轉。

---

## 6 · 推桿與叉口板

1. **下顎推桿**(6mm)放在下顎凸輪(x=70)上,寬腳朝下、桿身朝後(y=74~84)。
2. **眼球推桿**(6mm)放在眼球凸輪(x=54)上,同樣朝後。
3. **轉頭叉口板** —— C 形開口**朝前**,把轉頭凸輪(x=124)整個框進叉口裡。
   上下兩條平行邊夾住 Ø40 的偏心圓,**間隙只有 0.2mm**,這是它上下都被強迫帶動的原因,
   所以這片不需要橡皮筋。
4. 蓋上**中段導板**(z=70),三個開口讓兩支推桿和頸脊穿過。
5. 兩片**轉頭導片**黏在頂板下方 x=119 與 x=126,形成叉口板的導引通道。
6. 蓋上**頂板**。

> **驗**:兩支推桿在槽裡能上下滑順、不左右晃;叉口板上下走 **16mm**。

---

## 7 · 轉盤組

由下往上疊,全部黏成一體(中央都是 8.6×6.6 方孔):

```
撥臂(18×7)      z = 81~84   ← 末端裝 Ø4 撥銷,插進叉口板的 45° 斜槽
下盤(Ø30)        z = 84~87   ← 在頂板下面
凸台(Ø20,2層)   z = 87~93   ← 穿過頂板的 Ø20.6 孔
壓片(Ø30)        z = 93~96   ← 在頂板上面
```

下盤在頂板下、壓片在頂板上 → **轉盤被頂板夾住**,拔不出來也掉不下去。
凸台那 12mm 就是頸脊的導套,不要為了省事做薄。

頸脊方棒從下面穿過方孔 —— **可以上下滑、不能相對轉**,點頭與轉頭就是這樣分開的。

> **驗**:轉曲柄一圈,轉盤應該左右擺 **±15.5°**,而且頸脊跟著轉但仍能上下滑。

---

## 8 · 頭部

1. **頭骨主片 ×2**(68×91,含兩眼窩、鼻孔、四個 Ø4 銷孔)。
2. **下顎**(54×61,6mm)夾在兩片主片之間。
   > 下顎是**一整片**:碗形本體、往上的兩支升支(帶滑槽)、往下的兩個榫耳,
   > 全部在同一個輪廓裡,切出來就是一片,不用黏。
3. **眼球橫桿**(86×32)放在後片後面。它的左端也是一整片,榫已經長在上面。
4. 四個 **3×6 滑榫**黏進頭骨主片的方孔,穿過「主片 + 升支 / 橫桿 + 主片」:
   - 下顎滑榫 14 長 ×2:穿 前片(51~54)+ 下顎(54~60)+ 後片(60~63)
   - 眼球滑榫 18 長 ×2:穿 前片 + 後片 + 眼球桿(63~66)
   - 下顎銷:x = 76、104,z = 156
   - 眼球銷:x = 62、118,z = 176 —— 要離眼窩夠遠,不然孔會咬進眼窩
   下顎和眼球桿就是吊在這四個榫上,靠自己的長槽上下滑,**掉不出來**。
5. **受推板套上榫耳**:
   - 下顎底部中央的兩個 5×4 榫耳(x=83~88、92~97),穿過下顎受推板的兩個榫孔,上膠。
     榫耳長在碗底最低處 —— 碗形下緣往兩側一路翹到 z=141,只有中間那段有實料。
   - 眼球受推板的榫,插進眼球橫桿的榫孔,上膠。
   > 這裡千萬不要只用對接。3mm 板對接的膠合面太小,一推就開。
6. **頸脊接合塊**(20×26)立著黏在頭骨後片與頸脊之間(y=63~66)。
7. 整顆頭插上頸脊。

> **驗**:頭在最低點時,下顎最低處離頂板還有 **11.8mm**。
> 頭轉到 ±15.5° 時,兩片受推板都還壓在推桿頂端上(沒有滑出去)。

---

## 9 · 橡皮筋

- **下顎推桿**、**眼球推桿**各拉一條細橡皮筋往下。
- 為什麼非加不可:3mm 板的下顎自重只有 **0.045 N**、眼球桿 **0.033 N**,
  這個力連導槽的摩擦都贏不了,不加的話推桿會停在半空中不下來。
- **轉頭叉口板不用**(已經是強制驅動)。點頭升降板也不用(整顆頭壓著)。

---

## 10 · 定相位、上膠

慢慢轉曲柄,一片一片調凸輪角度,滿意了再上膠固定在軸上。

建議相位(第 4 步那張表):下顎 0° / 點頭 90° / 眼球 180° / 轉頭 270°。
模擬跑出來的效果:

| 曲柄 | 點頭 | 下顎開 | 轉頭 |
|---|---|---|---|
| 0° | 4.0 | 8.3 | 0° |
| 60° | 0.5 | 10.7 | −13.4° |
| 120° | 0.5 | 3.4 | −13.4° |
| 180° | 4.0 | 1.1 | 0° |
| 240° | 7.5 | 3.5 | +13.4° |
| 300° | 7.5 | 5.9 | +13.4° |

四個動作錯開,不會同時發生。想改「表情節奏」就轉凸輪相位,不用改任何零件。

---

## 順不順的小訣竅

- 凸輪與推桿的接觸邊磨圓、上蠟 —— 摩擦小、聲音脆。
- 導槽比桿寬 0.5mm 就好,太鬆會晃、太緊會卡死。
- 榫孔配合公差單邊 0.1mm(切割檔已經留好)。雷射有割縫,實際可能更鬆,榫上多塗點膠。
- 孔跟孔、孔跟輪廓之間都留了 2mm 以上的肉厚(切割檔產生時會自動驗)。3mm 合板再薄就容易崩。
- 轉不順就先拆橡皮筋,單獨轉曲柄找卡住的地方,不要一開始就整台調。

---

## 想看它動

打開 `sim.html`(或網站的「3D 模擬」),右邊切「修正版」。
右側面板有 15 項幾何檢查和完整的約束盤點(每個零件的每個自由度被什麼固定住)。
`node collide.js` 可以重跑干涉掃描,`node bom.js` 重出零件表,`node export-cut.js` 重出切割檔。

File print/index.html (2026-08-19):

# STL 下載

兩種印法選一種。列印參數與公差測試流程見 README.md, 還沒印過的先看3D 模擬。

## A. 列印原生版(免膠 10 件,推薦)

組裝照列印版組裝說明。

檔案 | 零件 | 件數 | 列印方向
hp-01-body.stl | 箱身(底板+四牆) | 1 | 開口朝上
hp-02-cap.stl | 頂蓋(含導套與壓入唇) | 1 | 檔已翻好,照印
hp-03-cam.stl | 偏心凸輪(D 孔) | 1 | 平躺
hp-04-spacer.stl | 間隔套 | 2 | 站著
hp-05-follower.stl | 推桿 | 1 | 平躺
hp-06-heart.stl | 心(換紅色料) | 1 | 平躺
hp-07-crank.stl | 曲柄臂(D 孔) | 1 | 平躺
hp-08-shaft.stl | 軸 Ø6×92(帶 D 面) | 1 | 平躺,D 面朝下
hp-09-handle-pin.stl | 手把銷 | 1 | 帽朝下站著

## B. 板件直印版(跟雷切檔同幾何,16 件,要上膠)

組裝照木板版組裝說明(疊層那步跳過),PLA 用瞬間膠。

檔案 | 零件 | 厚 | 件數
heart-01-base.stl | 底板 | 3 | 1
heart-02-side.stl | 側板 | 3 | 2
heart-03-top.stl | 頂板 | 3 | 1
heart-04-skirt.stl | 前後裙板 | 3 | 2
heart-05-guide-side.stl | 導片(左右) | 3 | 2
heart-06-guide-frontback.stl | 導片(前後) | 3 | 2
heart-07-cam.stl | 偏心凸輪(全厚) | 9 | 1
heart-08-crank.stl | 曲柄臂(全厚) | 6 | 1
heart-09-collar.stl | 軸環 | 3 | 2
heart-10-follower.stl | 推桿(全厚) | 6 | 1
heart-11-heart.stl | 心 | 3 | 1

另需:Ø6 圓棒兩段(軸 92mm、手把 34mm),竹筷可替代。

誠實聲明:兩版都通過模擬三層驗證,但都還沒實際印過。印了歡迎回報。

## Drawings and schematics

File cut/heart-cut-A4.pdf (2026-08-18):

側板 | 側板

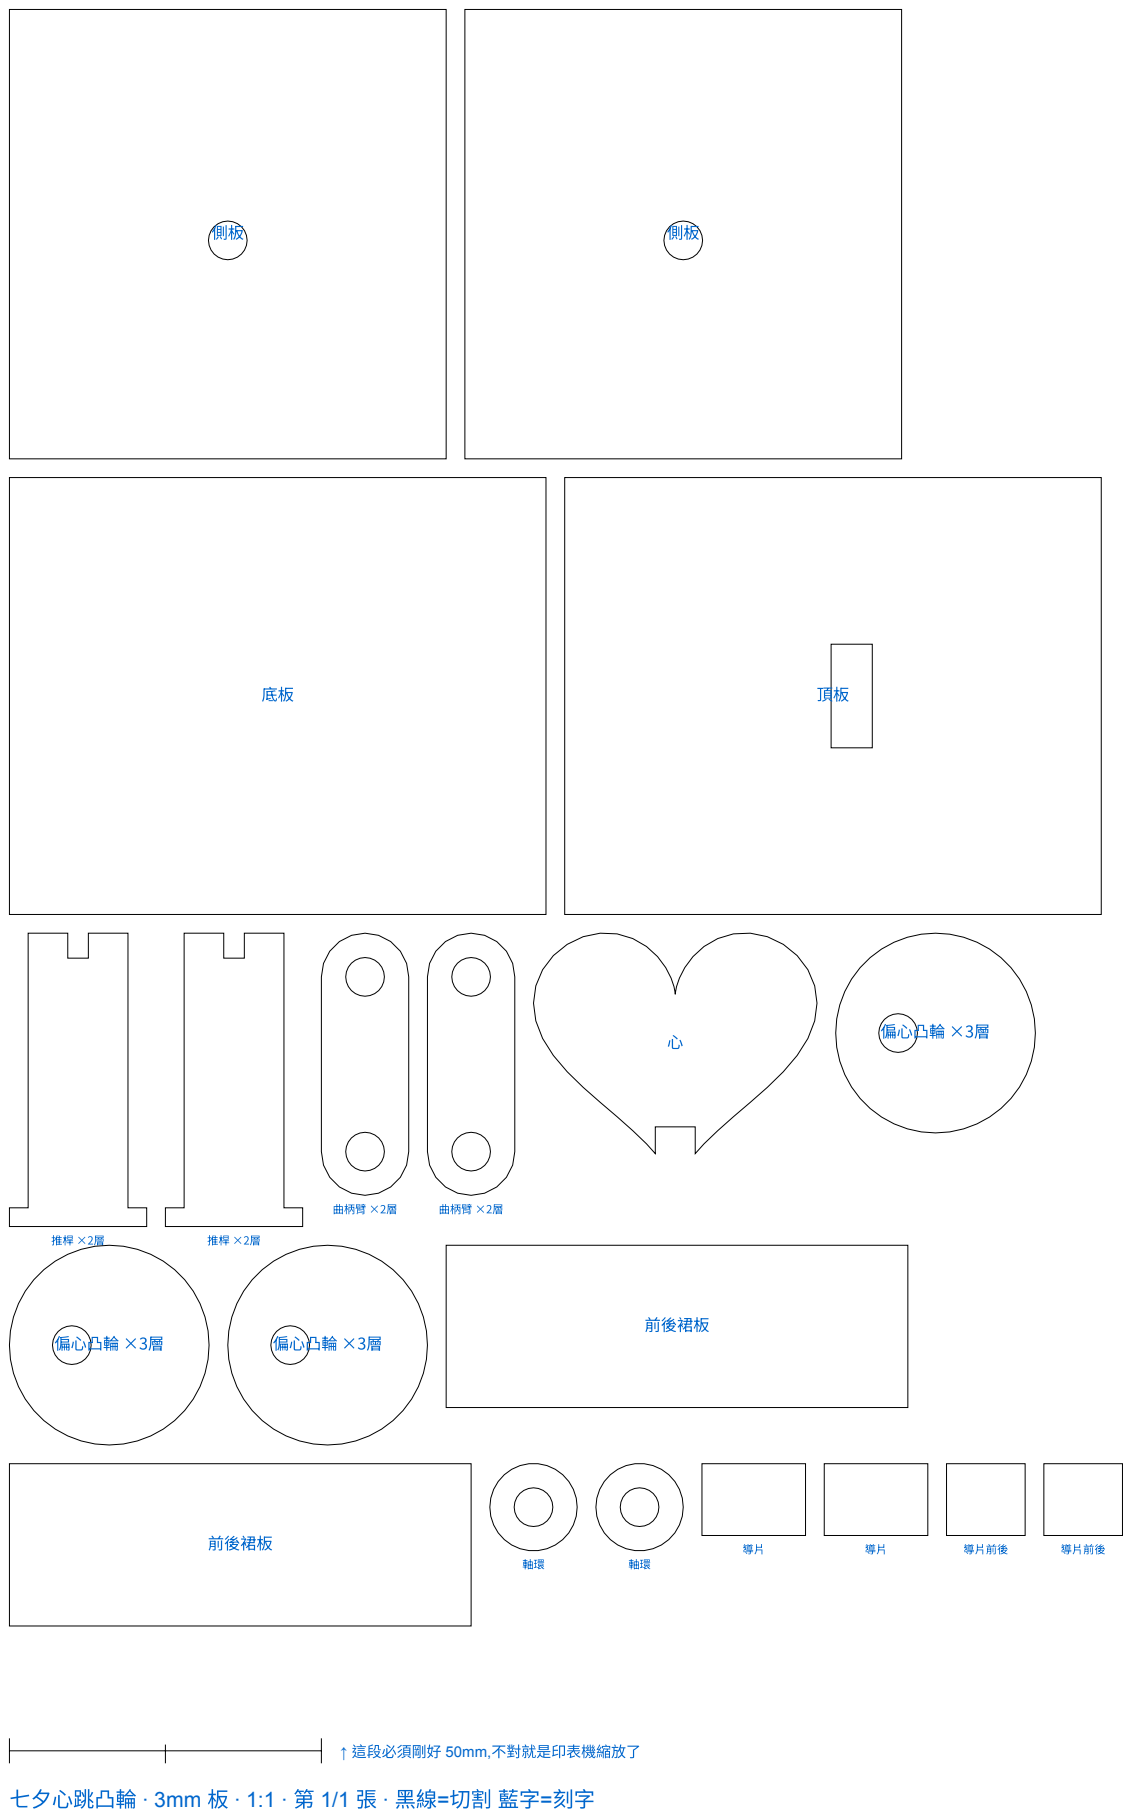
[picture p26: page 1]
↑ 這段必須剛好 50mm,不對就是印表機縮放了; 曲柄臂 ×2層; 前後裙板

七⼣⼼跳凸輪 · 3mm 板 · 1:1 · 第 1/1 張 · ⿊線=切割 藍字=刻字

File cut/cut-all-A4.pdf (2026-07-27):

↑ 這段必須剛好 50mm,不對就是印表機縮放了

骷髏頭凸輪玩具 · 3mm 板 · 1:1 · 第 1/5 張 · ⿊線=切割 藍字=刻字

眼球推桿 ×2層 | 眼球推桿 ×2層

底板

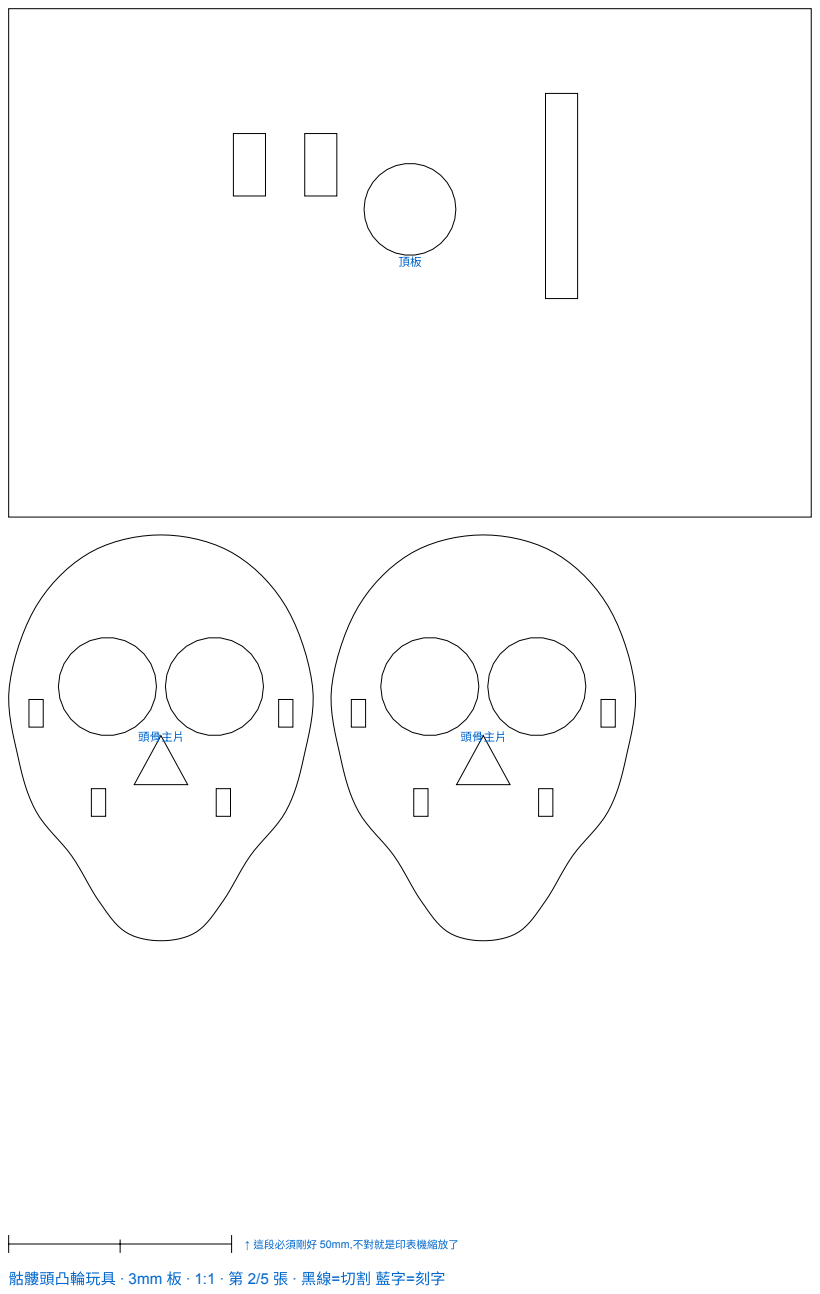
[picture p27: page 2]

骷髏頭凸輪玩具 · 3mm 板 · 1:1 · 第 2/5 張 · ⿊線=切割 藍字=刻字

骷髏頭凸輪玩具 · 3mm 板 · 1:1 · 第 3/5 張 · ⿊線=切割 藍字=刻字

前板

後板

左側板

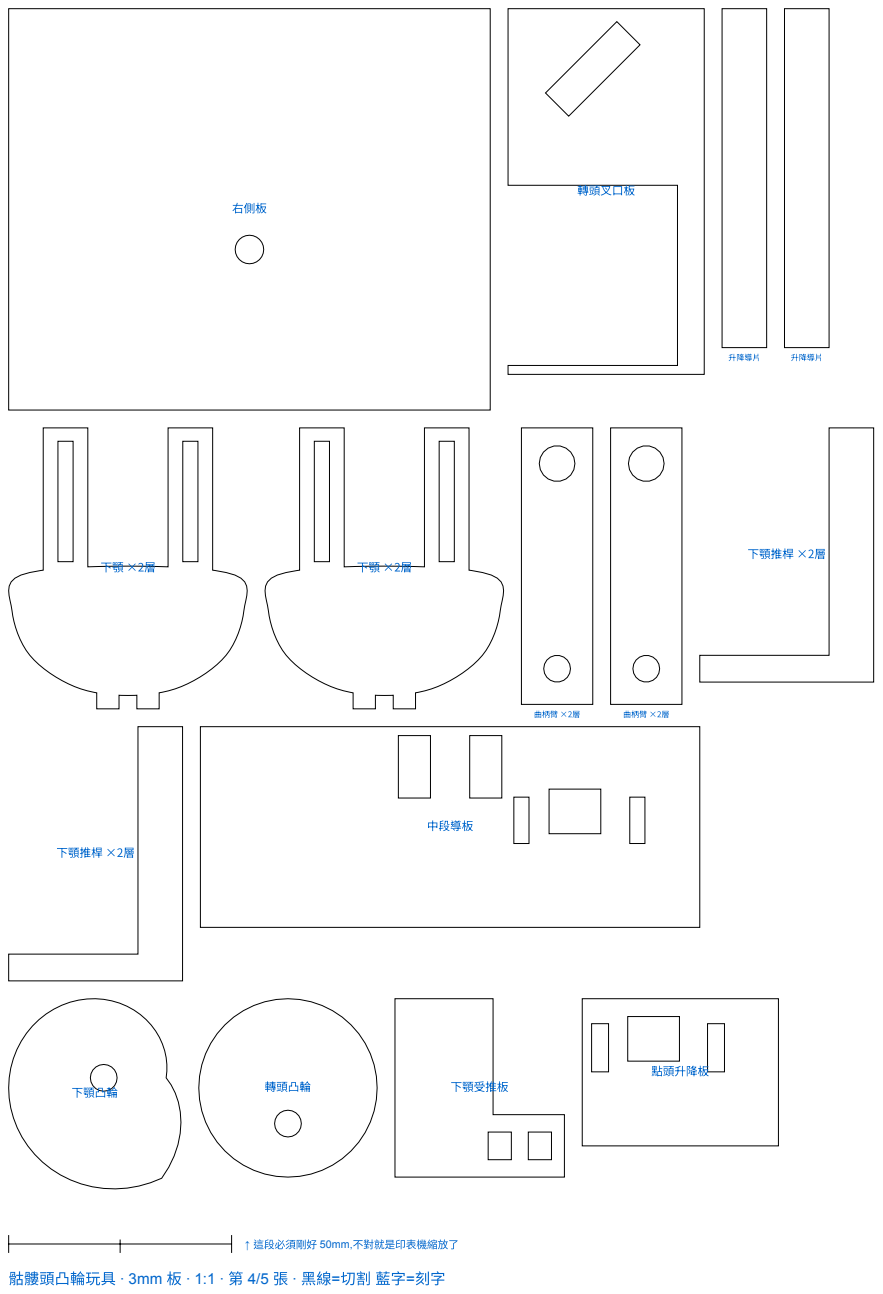
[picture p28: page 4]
右側板; 轉頭叉⼝板; 升降導⽚; 曲柄臂 ×2層; 下顎推桿 ×2層; 中段導板; 下顎凸輪; 轉頭凸輪; 下顎受推板; 點頭升降板

骷髏頭凸輪玩具 · 3mm 板 · 1:1 · 第 4/5 張 · ⿊線=切割 藍字=刻字

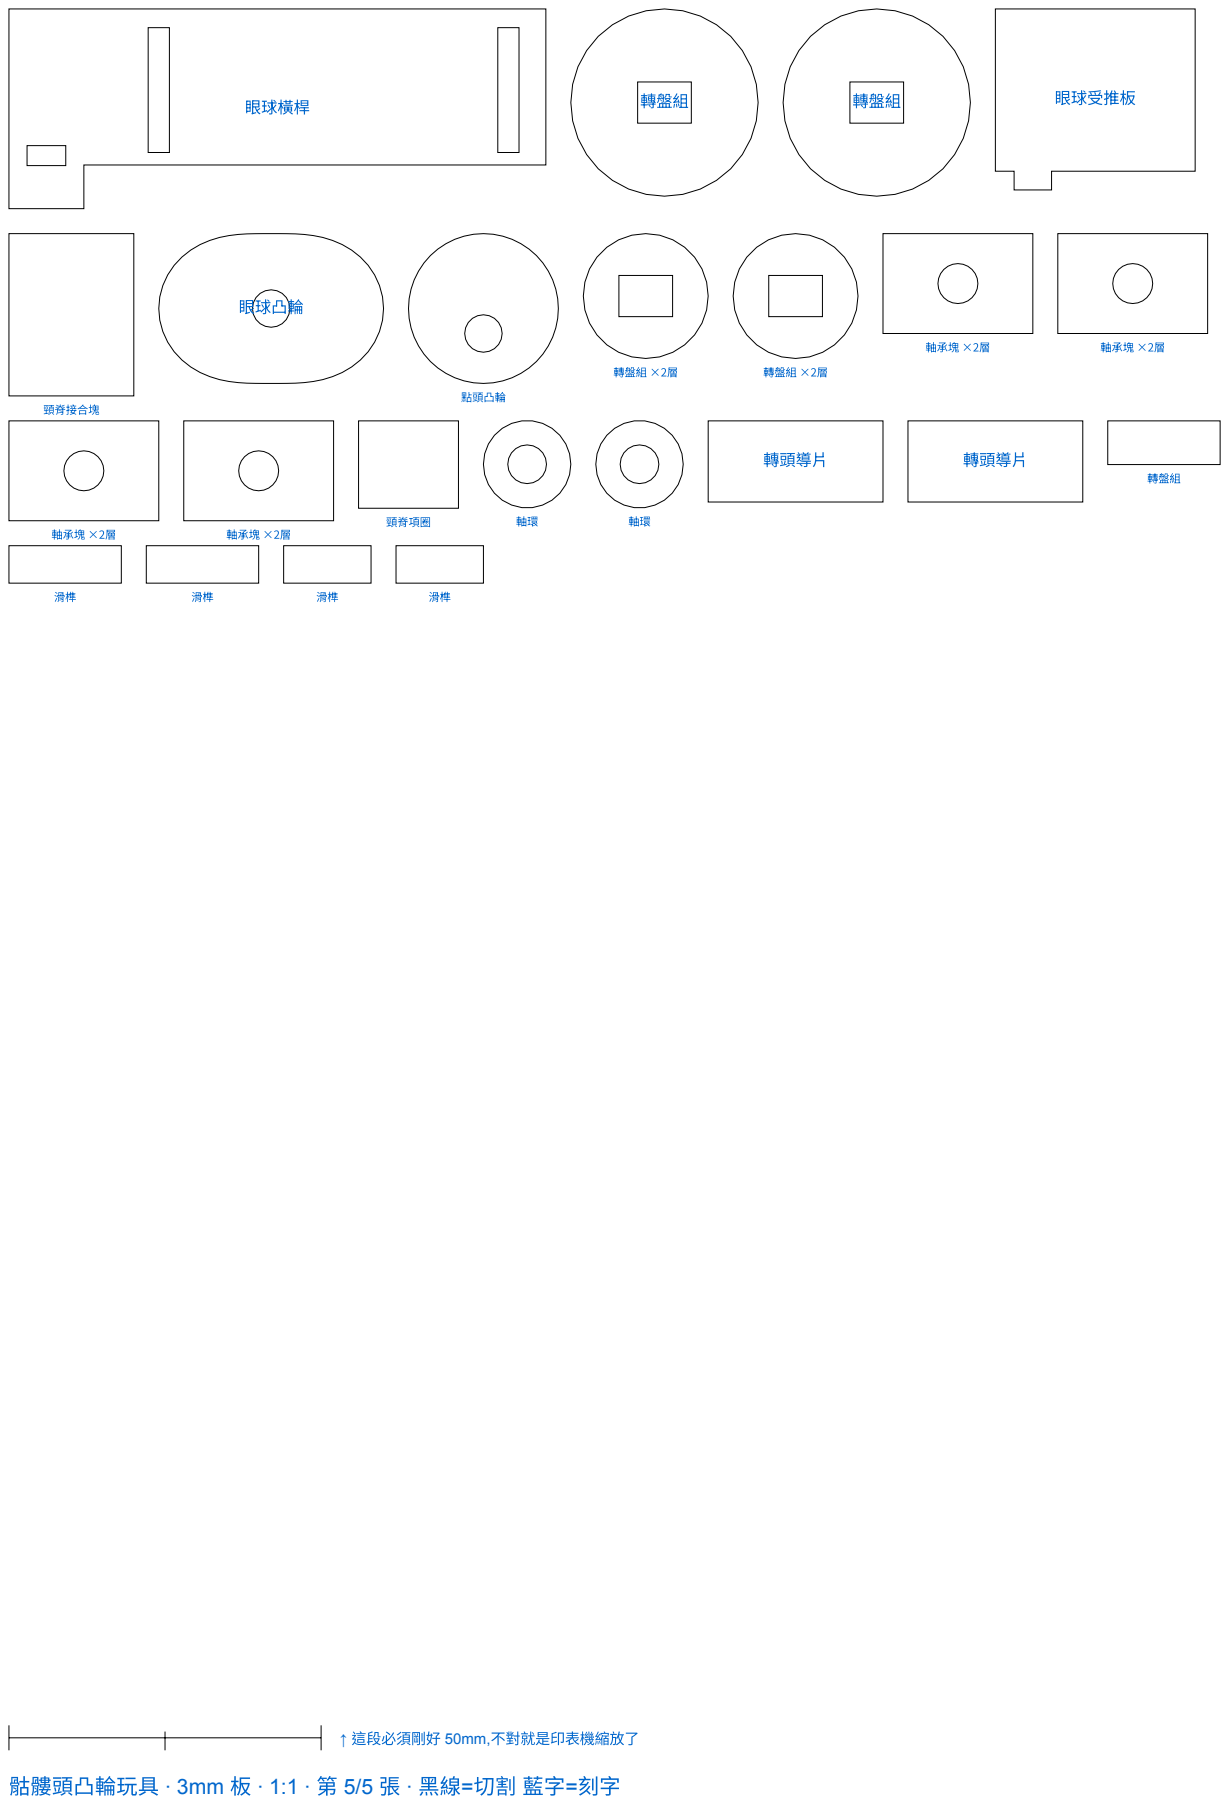
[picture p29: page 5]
眼球橫桿; 轉盤組; 眼球受推板; 頸脊接合塊; 眼球凸輪; 點頭凸輪; 轉盤組 ×2層; 軸承塊 ×2層; 頸脊項圈; 轉頭導⽚

骷髏頭凸輪玩具 · 3mm 板 · 1:1 · 第 5/5 張 · ⿊線=切割 藍字=刻字

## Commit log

2026-07-27 init: 骷髏頭凸輪玩具 —— 樣板驗證、修正設計、3D 模擬與雷切檔
    起因是一份 AI 產生的 1:1 裁切樣板 PDF。圖面乍看很完整(尺寸線、鑽孔中心、
    組裝順序、相位圖都有),但把向量座標解出來重算後,找到七個致命問題,
    其中轉頭那一路的自由度是 0 —— 缺球接頭的空間連桿,零件全對也轉不動。
    這份包含重新推導的機構、驗證工具鏈,以及可直接下雷切的 1:1 檔案:
    - 斜槽 + 叉口取代空間連桿,方孔花鍵讓點頭與轉頭解耦
    - 15 項幾何檢查 + 131,436 點的全零件干涉掃描(轉一圈 72 個角度零干涉)
    - 逐件 6 自由度約束盤點,分形封閉與力封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
    [cut-1.dxf, cut-2.dxf, cut-3.dxf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]
2026-07-27 fix: 榫接開在沒有材料的地方 —— 補上「孔必須落在輪廓內」的零件自檢
    亞澤看切割檔時發現下顎的兩個榫孔有一個整個飄在輪廓外。追下去發現
    干涉掃描永遠抓不到這類錯:不存在的材料不會跟任何東西相撞。
    補上零件自檢後一次抓到五個壞孔,其中三個是先前都沒發現的:
    - 下顎榫孔 ×2:下顎是碗形,下緣從中央 z=122 往兩側翹到 z=141,
    原本開在 x=66~82 的榫孔那裡根本沒料 → 改成碗底最低處(x=84~96)的榫耳
    - 轉頭叉口板:45° 斜槽頂端超出板子上緣 → 板高 36 改 40
    - 點頭升降板:導柱孔破出後緣 → 導柱由 (114,74) 移到 (114,70)
    -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
    [cut-1.dxf, cut-2.dxf, cut-4.dxf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]
2026-07-27 fix: 眼窩咬孔、下顎被拆成三片 —— 補上肉厚自檢與單件自檢
    亞澤看切割檔連續抓到兩件事,兩件都是既有檢查結構上看不到的:
    1. 眼球滑銷孔咬進眼窩(銷心離窩心 11.7mm,而 11+2.1=13.1)
    → 新增肉厚自檢:量孔↔孔、孔↔輪廓的最短距離,下限 2.0mm
    一跑抓到 13 處,最薄 0.13mm。滑銷改 x=62/118,肉厚變 4mm
    2. 下顎在切割檔裡是三片(本體+2榫耳+2升支),同名但分開畫,要靠膠黏
    → 寫 addRect 外形合併,把榫耳/升支沿輪廓上下緣併進本體 → 真正一整片
    → 新增單件自檢:同名零件同平面又相接就報錯
    順帶把自檢的過濾移到最前面,原始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
    [cut-1.dxf, cut-2.dxf, cut-4.dxf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]
2026-07-27 feat: 導柱/滑銷/軸環全改板材卡榫 —— 圓棒從七種縮到兩支
    亞澤問能不能少用圓棒。逐項判之後八成可以:
    - 升降板導柱 Ø4×2 → 升降導片 10×76 板材 ×2
    封閉長槽比圓孔多定住一個旋轉自由度,其實比圓柱好
    - 下顎/眼球滑銷 Ø4×4 → 3×4 板材滑榫 ×4,頭骨主片改開方孔
    - 軸環 Ø14×2 → 板材圓片(中心 Ø6.2)
    保留圓棒的只剩兩支,理由寫進報告:
    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
    [cut-1.dxf, cut-2.dxf, cut-4.dxf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]
2026-07-27 fix: 滑榫斷面 3×4 太脆 → 加高到 3×6
    亞澤問滑榫的數量和厚度對不對。量過:數量 4 個(下顎 ×2、眼球 ×2)、
    厚度 3mm 單層、長度 14/18mm 都對,穿過的層數也對。
    但 3×4×14 的碎片雷切完幾乎一折就斷。加高到 3×6:
    - 頭骨主片的方孔 3.2×4.2 → 3.2×6.2
    - 下顎升支長槽 153~177 → 152~179,升支跟著加高 2mm 留肉
    - 眼球橫桿長槽 173~192 → 173~193
    四層自檢全過、零干涉、15 項幾何檢查全過。切割檔與說明書重出。
    [cut-2.dxf, cut-4.dxf, cut-5.dxf]
2026-08-17 promo footer v10:加站台開啟計數
    只送站名到 k-rider worker 的 /hit,後端只記「哪天、哪站、被打開幾次」,
    不存 IP、不設 cookie、不記 referrer。有一半的作品是純靜態沒後端,
    以前根本不知道有沒有人在用。
2026-08-17 promo footer:版號標記補正 v9→v10
    apply.py 的 VERSION 早就是 10,但模板裡那行註解還寫 v9(要人工同步、漏改了),
    於是每次捲版都重寫全部檔案卻永遠升不上去。版號改成由 apply.py 代入,只有一個來源。
2026-08-18 chore: promo-footer 升到 v11（贊助文案不再用「長出」）
    「咖啡因進入亞澤體內，程式碼就會長出來」——「長出」是禁用的有機隱喻，
    改成「程式碼就會自己寫完」。skill 樣板已在源頭改掉，這裡跟著捲版。
2026-08-18 fix(sim): 手機觸控支援——canvas 設 touch-action:none,單指旋轉、雙指捏合縮放與平移
2026-08-18 fix(sim): 手機版面——側欄改直排接在畫布下方,數值浮層縮小,窄螢幕鏡頭拉遠讓整台機構入鏡
2026-08-18 feat: 七夕限定「心跳凸輪」入門版——heart.html 3D 模擬+8 項整圈檢查,切割檔由模型產生(15 片一張 A4),站內導覽與下載區同步
    [heart-cut-1.dxf]
2026-08-18 fix(heart): 凸輪相位符號反了,推桿半週期陷進凸輪——干涉掃描抓到後修正;掃描留成 heart-collide.js(36 角度零干涉)
2026-08-18 style(heart): 配色整理——推桿改木色(與心讀成同一支木柄)、凸輪改玫瑰色與心同家族
2026-08-18 feat(heart): 導片 2→4 圍成導套(防卡滯比 5→1.0)+零件自檢腳本(抓到心輪廓自交並修正);站內入口暫時下架當直播彩蛋
    [heart-cut-1.dxf]
2026-08-18 chore: 加 .nojekyll——純靜態站跳過 Jekyll,避免 legacy pages build 卡死
2026-08-18 feat(heart): 拆解接頭按鈕——心上滑露出十字插槽,講解咬合結構用
2026-08-18 feat(heart): 裝配容差——凸輪加厚成 3 層(軸向 ±1.5mm)、推桿改 T 型腳(接觸餘裕 2→5mm);行程檢查高低標籤修正;竹筷替代軸註記
    [heart-cut-1.dxf]
2026-08-18 fix(heart): 接頭重設計——原本兩槽互疊成同一段空腔,y 向零咬合(假接頭);改心底加 12mm 矩形柄與推桿做正規十字搭接(各切 5mm 中線相會);另修參數改名漏網的 heartSlotD 造成叉槽 NaN
    [heart-cut-1.dxf]
2026-08-18 fix(heart): 接頭改錯位搭接(yazelin 提出)——心下沉讓兩槽錯開:心槽壁跨桿(x)、叉齒夾心板(y)、槽頂面坐叉底面(z),四面咬合;心外觀維持完整,槽藏在桿後
    [heart-cut-1.dxf]
2026-08-18 docs(heart): 組裝步驟同步凸輪三片疊層,並明寫軸孔整圈上膠
2026-08-18 feat(heart): 整機爆炸圖滑桿(各件沿裝配方向拉開)+組件顯隱開關列——對照組裝六步用(yazelin 提出)
2026-08-18 docs(heart): 導套組裝改用推桿當治具的順序;下載區補 kerf 說明
2026-08-18 docs(heart): 組裝防卡死——導片黏製時桿身包紙墊隙(靠緊黏=零間隙必卡),補疊層磨齊與板厚公差提醒
2026-08-18 docs(heart): 組裝六步擴寫成動作+注意+驗收,加「最容易裝錯的五件事」防呆清單
2026-08-18 docs(heart): 組裝說明專頁 heart-assembly.html(HEART-ASSEMBLY.md 產生,七步+逐步驗收+防呆五清單)+DESIGN-RULES.md 設計規則檢查表
2026-08-18 fix(heart): 心跳系列兩頁改用自己的子導覽(模擬/組裝/切割檔),不再指向骷髏的組裝頁
2026-08-18 fix(heart): 品牌字改「七夕限定 · 心跳凸輪」,骷髏頭改為導覽尾端的返回連結
2026-08-18 docs(heart): 組裝頁每步附 3D 完成狀態參考圖(顯隱系統逐步出圖);膠水指引修正——白膠為主、熱熔膠禁用於配合面、竹筷黏合段磨毛;橡皮筋移除(自重回位餘裕計算 386rpm 才跳離)
2026-08-18 feat(heart): 補 heart-cut-A4.pdf(1:1 列印描圖用),下載連結改 PDF 優先、SVG/DXF 標明雷切用
2026-08-18 feat(heart): 前後裙板 ×2 閉環箱體(yazelin 指出只有兩面牆會歪斜);切割檔改兩張 A4(SVG/DXF/PDF 重出),組裝第 2 步與步驟圖同步
    [heart-cut-1.dxf, heart-cut-2.dxf]
2026-08-18 docs: 組裝頁補實作註記——實體有手工修配,照檔切仍需現場微調;模擬給九成,最後一成靠現場
2026-08-18 fix(heart): 底/頂板左緣 20mm 廢料修掉(yazelin 指出)——留 6mm 膠肩,板變 86×70;切割檔排回一張 A4,PDF/步驟圖/文案同步
    [heart-cut-1.dxf, heart-cut-2.dxf]
2026-08-19 og: 全站加 Open Graph 標籤與 og.jpg(實體成品照 1200x630)
2026-08-19 og: 改成有標題文字的版面(左圖右字,簡報同款配色)
2026-08-19 og: 標籤列加 DIY 手作
2026-08-19 og: 副標改為模擬裡修到會動,真的切出來了
2026-08-19 og: 副標拿掉驚訝語氣,改為模擬裡修到會動再用線鋸切出來
2026-08-19 print: 心跳凸輪 3D 列印版 STL(11 種 16 件,疊層件印全厚)+匯出腳本+列印說明
    全件通過水密檢查與 BOM 尺寸核對;未實印,說明有寫。
    [heart-01-base.stl, heart-02-side.stl, heart-03-top.stl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]
2026-08-19 print: 心跳凸輪 3D 列印原生版(heart-print.html 獨立模擬頁+9 種零件 STL+免膠組裝五步)
    - 13 項幾何檢查全綠、36 角度干涉掃描零干涉(同件互碰排除)、STL 逐殼水密+繞向+尺寸核對全過
    - D 型軸傳扭力、頂蓋含導套與壓入唇一體印、間隔套取代軸環
    - 板件直印版挪到 print/flat/,README 改寫成雙版本
    - 未實印,誠實聲明照寫
    [heart-01-base.stl, heart-02-side.stl, heart-03-top.stl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]
2026-08-19 print: 列印版完整組裝說明頁(五步各附 3D 完成狀態圖)+導覽互連
2026-08-19 print: 補 print/index.html 下載頁(Pages 不列目錄,原連結 404)
2026-08-19 prose: 清掉「切出來真的會動」的驚訝語氣,改為如預期會動
2026-08-20 reveal: 心跳凸輪解除隱藏(README+全站導覽入口,直播已揭曉)
